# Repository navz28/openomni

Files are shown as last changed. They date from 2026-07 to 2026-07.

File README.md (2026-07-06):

# OpenOmni 🏃‍♂️🕹️

**Treadmill omnidireccional pasiva, DIY e imprimible en 3D — clon funcional del Virtuix Omni One** con madera, tubo de PVC/fierro, piezas de bicicleta, un resorte de gas hidroneumático y electrónica estilo SlimeVR.

> Objetivo: la misma experiencia (caminar/correr 360° dentro de VR sin marearse) por **~US$250–430** en vez de **US$2,600–3,500**.

## Principio de diseño
Igual que el Omni One, **no hay motores**: un **cuenco cóncavo parabólico** de baja fricción + **calzado deslizante** hacen que la gravedad recentre el pie tras cada paso. Un **brazo articulado posterior** que gira 360° sobre un rodamiento (de bici) sostiene al usuario por un **chaleco**, con un **resorte de gas** para agacharse/saltar. Sensores **IMU** en los pies traducen las zancadas a locomoción, presentándose a la PC como un **mando USB** (sin drivers propietarios).

## Contenido del repo
```
treadmill/
├── README.md                 <- esto
├── index.html                <- SIMULACIÓN INTERACTIVA 3D (Three.js) para GitHub Pages
├── geminideepresearch.txt    <- investigación de partida sobre el Omni One
├── docs/
│   ├── 01-lista-componentes.md   <- BOM por subsistema + costos  (ENTREGABLE 1)
│   ├── 02-diagrama-fuerzas.md     <- física + hidráulica + IK     (ENTREGABLE 2)
│   └── 03-referencia-woodt.md     <- armado en madera (octágono, video/WoODT)
├── cad/
│   ├── openomni.scad             <- modelo 3D paramétrico         (ENTREGABLE 3)
│   ├── README.md                 <- cómo renderizar/exportar STL
│   ├── assembly.png / side.png   <- renders del conjunto
│   └── *.stl                     <- piezas imprimibles exportadas
└── firmware/                     <- código + drivers de sensores  (ENTREGABLE 4)
    ├── README.md                 <- cableado, librerías, flasheo
    ├── openomni_protocol.h       <- trama pie→hub (0x55 + seq + CRC16)
    ├── foot_tracker/             <- ESP32-C3 + IMU + FSR (×2)
    ├── hub/                      <- ESP32-S3 → mando USB
    └── pc_bridge.py              <- driver PC alterno (modo serie)
```

## Subsistemas (resumen)
| # | Subsistema | Material clave | Ref. |
|---|---|---|---|
| A | Cuenco cóncavo 13° Ø1.2 m (**octágono de 8 módulos**, estilo WoODT) | contrachapado + piel laminada + HDPE/hardboard + silicona | docs/01 §A |
| B | Estructura + base | fierro 40–50 mm / madera + **lastre 25–30 kg** | docs/01 §B |
| C | Brazo articulado + hub 360° + arnés | tubo acero + **rodamiento/pedalier de bici** + **gas strut** | docs/01 §C |
| D | Calzado deslizante | impreso 3D + **PTFE/UHMW** | docs/01 §D |
| E | Trackers de pie | ESP32-C3 + MPU-9250 + FSR + LiPo | firmware/ |
| F | Hub / puente PC | ESP32-S3 (mando USB) | firmware/ |

## Simulación interactiva (webapp)
`index.html` es un **gemelo digital** en Three.js (autocontenido, para **GitHub Pages**):
- **Humanoide paramétrico** (peso 40–120 kg, altura 1.50–2.00 m) que **camina** en el cuenco.
- **Brazo hidráulico tipo mochila** con **hub que gira 360°** e **IK de 2 eslabones** que se adapta a la talla; botón **«Dejarse caer»** que comprime el gas strut.
- **Flechas de fuerza** en vivo (peso, normal, recentrado, arnés, strut) con lecturas numéricas.
- **Cuenco octagonal** de 8 módulos; **piezas impresas 3D coloreadas** (naranja) e **hidráulica** (turquesa) con leyenda.
- **Ensamblaje animado** (botones Ensamblar/Explotar) y **descargas STL**.

Preview local (tienes node): `npx serve .` y abre `http://localhost:3000` (o abre `index.html` en tu Chromium). Despliegue en Pages: ver abajo.

## Números de diseño (del análisis de fuerzas)
- Usuario máx **113 kg** (W=1110 N); pendiente del cuenco **13°** → recentrado ≤250 N/paso.
- Fricción objetivo **μ < 0.12** (PTFE/UHMW + silicona) = requisito #1.
- Chaleco: **600 N** horiz + 350 N vert. Brazo inferior **tubo 40×40×3** (SF 1.9). Poste **50×50×3** (SF 3.3).
- **Vuelco: hay que lastrar ≥25–30 kg** o vuelca en los saltos (por eso el Omni pesa 70 kg a propósito).

## Orden de construcción sugerido
1. **Cuenco** (A): corta las 16 costillas con la plantilla `cad → rib_template.stl`, ensámblalas radiales, forra, alisa y sella. Prueba la fricción con el calzado antes de seguir.
2. **Base + poste + lastre** (B).
3. **Hub + brazo + arnés** (C): monta el rodamiento de bici, los eslabones y el gas strut; ajusta para tu altura.
4. **Calzado** (D): imprime, pega los PTFE.
5. **Electrónica** (E/F): flashea los 2 pies + el hub, calibra el "adelante", mapea el stick en SteamVR.

## Estado
- [x] Investigación consolidada (+ referencia de armado en madera WoODT)
- [x] Lista de componentes (BOM)
- [x] Diagrama de fuerzas y cálculos (+ física de la hidráulica + IK)
- [x] Modelo 3D en OpenSCAD (renders + STL validados)
- [x] Firmware trackers + hub + puente PC (protocolo validado)
- [x] Webapp interactiva (humanoide, fuerzas, ensamblaje, hidráulica)
- [ ] **Siguiente:** construir el prototipo del cuenco y medir la fricción real (μ) del par superficie/PTFE.

## Desplegar en GitHub Pages
El repo ya está listo (git inicializado y commiteado). Para publicarlo:
```bash
# 1) re-autenticar gh (el token del keyring caducó)
gh auth login
# 2) crear el repo y subir  (público para que Pages funcione en cuenta free)
gh repo create openomni --public --source=. --remote=origin --push
# 3) activar Pages sirviendo desde la raíz de main
gh api -X POST repos/:owner/openomni/pages -f source[branch]=main -f source[path]=/ 2>/dev/null || \
  echo "Actívalo a mano: Settings → Pages → Branch: main / (root)"
```
La app quedará en `https://<usuario>.github.io/openomni/`. Los STL (`cad/*.stl`) se sirven junto a la web para las descargas.

## Fuentes de la investigación
- Virtuix Omni One (specs, patentes, SDK): `geminideepresearch.txt`
- Builds DIY de referencia (ángulo de cuenco 13–15°, deslizadores): [Hackaday](https://hackaday.com/2014/02/18/low-budget-omnidirectional-treadmill/), [Instructables TolDish](https://www.instructables.com/TolDish-a-DIY-Omnidirectional-Treadmill/)
- Tracking de pies open-source: [SlimeVR-Tracker-ESP](https://github.com/SlimeVR/SlimeVR-Tracker-ESP)

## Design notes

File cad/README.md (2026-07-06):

# OpenOmni — Modelo 3D (OpenSCAD)

Modelo **paramétrico** de toda la treadmill en `openomni.scad`. Cambiando las variables de la cabecera (radio `R`, ángulo del borde `edge_angle`, nº de costillas `n_ribs`, etc.) se re-genera todo, incluidas las plantillas de corte.

## Requisitos
OpenSCAD 2021.01+ (ya instalado: `/usr/bin/openscad`).

## Ver el conjunto en la GUI
```bash
openscad cad/openomni.scad
```

## Seleccionar qué pieza mostrar/exportar
La variable `part` elige el objeto. Valores: `assembly`, `bowl`, `rib_template`, `overshoe`, `sensor_case`, `arm_hub`.

## Exportar STL de las piezas imprimibles
```bash
cd cad
openscad -o overshoe.stl    -D 'part="overshoe"'     openomni.scad   # calzado deslizante (x2, uno espejado)
openscad -o sensor_case.stl -D 'part="sensor_case"'  openomni.scad   # carcasa tracker IMU (x2)
openscad -o arm_hub.stl     -D 'part="arm_hub"'       openomni.scad   # abrazadera/hub del brazo
openscad -o rib_template.stl -D 'part="rib_template"' openomni.scad   # plantilla de UNA costilla
```
> `rib_template` es una lámina de 4 mm: imprímela, pégala sobre el contrachapado y usa el perfil para cortar las 16 costillas con sierra de calar. Las marcas grabadas cada 100 mm son las líneas de radio.

## Renderizar imágenes
```bash
DISPLAY=:0 openscad -o assembly.png --imgsize=1100,850 \
  --camera=0,0,0,62,0,32,0 --viewall --autocenter \
  --colorscheme=Tomorrow -D 'part="assembly"' openomni.scad
```
Ya generadas: `assembly.png` (isométrica) y `side.png` (lateral).

## Imprimir el calzado espejado
El pie derecho es el modelo tal cual; para el izquierdo, espeja en el laminador (o añade `mirror([0,1,0])` antes de `overshoe()`).

## Parámetros clave (cabecera del .scad)
| Variable | Valor | Significado |
|---|---|---|
| `R` | 600 | radio útil del cuenco (mm) |
| `edge_angle` | 13 | pendiente en el borde (°) — **no subir**, ver análisis de fuerzas |
| `n_ribs` | 16 | costillas radiales |
| `k` | derivado | coef. de la parábola `z=k·r²` |

## Piezas del modelo
- **Cuenco** (`bowl` + costillas): dish parabólico + 16 costillas radiales.
- **Estructura**: aro base, largueros, poste trasero 50×50, lastre.
- **Brazo articulado**: hub rotatorio, 2 eslabones, bisagra, gas strut, placa de chaleco.
- **Calzado** (`overshoe`): suela con rocker, 3 almohadillas PTFE Ø55, ranuras de correa, pod del sensor.
- **Carcasa sensor** (`sensor_case`): caja 52×40×26 con postes para ESP32 y ranura USB-C/LED.
- **Hub imprimible** (`arm_hub`): abraza el tubo del eslabón y aloja el rodamiento de bici (Ø42).

## Nota
Es un modelo de **diseño/fabricación y visualización**, no un gemelo CAD con tolerancias de máquina. Las piezas de madera/acero se cortan con las plantillas y las dimensiones de la BOM; las piezas imprimibles (calzado, carcasas, hub, abrazaderas) salen directas a STL.

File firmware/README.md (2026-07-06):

# OpenOmni — Firmware

Sistema de tracking de pies estilo **SlimeVR** adaptado a la treadmill omnidireccional. La treadmill es **pasiva** (no tiene motores); el firmware solo lee sensores y traduce el movimiento de los pies en locomoción para el juego.

## Arquitectura

```
   PIE IZQUIERDO                 PIE DERECHO
 ┌──────────────┐             ┌──────────────┐
 │ ESP32-C3     │             │ ESP32-C3     │
 │ + MPU-9250   │             │ + MPU-9250   │
 │ + FSR talon  │             │ + FSR talon  │
 │ + LiPo       │             │ + LiPo       │
 └──────┬───────┘             └──────┬───────┘
        │  ESP-NOW (2.4GHz, broadcast, 100 Hz)
        └───────────────┬────────────┘
                        ▼
                ┌───────────────┐
                │ HUB ESP32-S3  │  fusiona -> vector de locomocion
                │ USB HID nativo│  "soft decoupling" (rumbo de los pies)
                └───────┬───────┘
                        │ USB  (se ve como MANDO estandar)
                        ▼
                   PC / SteamVR / juego
```

- `foot_tracker/` — firmware del tracker de pie (×2). Driver I2C del IMU + fusión Mahony + detección de zancada + envío ESP-NOW.
- `hub/` — firmware del receptor. Recibe ambos pies, fusiona y **se presenta como un mando USB** (sin instalar drivers en la PC).
- `openomni_protocol.h` — trama compartida (preámbulo `0x55` + seq + CRC16), inspirada en el formato de los Foot Trackers del Omni One.

## ¿Por qué "mando USB" y no un driver propietario?

El hub ESP32-S3 usa USB HID nativo (TinyUSB) y aparece como un **gamepad estándar**. Así:
- **No hay que instalar ningún driver** en Windows/Linux.
- Funciona en **SteamVR** (locomoción por stick), en juegos planos y en cualquier motor.
- El stick izquierdo = vector de caminar; botón 1 = correr.

> Para *soft decoupling* real (caminar hacia un lado mientras miras a otro, como el Omni One) se puede escribir además un **driver OpenVR** que inyecte el vector en el espacio del jugador. Es opcional; el modo mando ya da locomoción omnidireccional relativa al cuerpo.

## Hardware y cableado (drivers de sensores)

### Tracker de pie (×2) — ESP32-C3
| Señal | Pin ESP32-C3 | A |
|---|---|---|
| I2C SDA | GPIO8 | MPU-9250 SDA |
| I2C SCL | GPIO9 | MPU-9250 SCL |
| FSR (ADC) | GPIO3 | divisor FSR↔10 kΩ a GND |
| LED estado | GPIO10 | LED + R330 a GND |
| VBAT (ADC) | GPIO2 | divisor 1:1 de la LiPo |
| 3V3 / GND | — | alimentación IMU y FSR |

**FSR (sensor de pisada):** `3V3 —[FSR]— A0 —[10kΩ]— GND`. Al pisar baja la resistencia → sube el ADC. Umbral en el código: `fsr > 400` (ajústalo).

**IMU:** el driver I2C está incluido en `foot_tracker.ino` (no usa librería externa). Detecta MPU-9250 (`WHO_AM_I=0x71`), MPU-6500 (`0x70`) o MPU-9255 (`0x73`). Config: accel ±4 g, gyro ±500 dps, DLPF 41 Hz, 200 Hz.
> Nota: la fusión es de **6 ejes** (accel+gyro). Es robusta para el rumbo a corto plazo de cada zancada. Si tu IMU trae magnetómetro (AK8963 en el MPU-9250, o un ICM-20948), puedes añadir su lectura para rumbo **absoluto** sin deriva — marcado en el código dónde iría.

### Hub — ESP32-S3
- Solo USB al PC. Botón **BOOT (GPIO0)** = recalibrar "adelante".
- (Opcional) OLED SSD1306 por I2C para ver estado/batería.

## Librerías necesarias

Todas vienen con el **core arduino-esp32 (v3.x)** — no hay que instalar terceros:
- `Wire`, `WiFi`, `esp_now` (ambos sketches)
- `USB`, `USBHIDGamepad` (solo el hub, requiere ESP32-S3)

Instala el core desde el Boards Manager de Arduino IDE: *"esp32 by Espressif"* (≥3.0.0).

## Flashear

### Trackers de pie
1. Abre `foot_tracker/foot_tracker.ino`.
2. En **un** tracker deja `#define THIS_FOOT FOOT_LEFT`; en el otro cámbialo a `FOOT_RIGHT`.
3. Placa: *ESP32C3 Dev Module*. Sube.

### Hub
1. Abre `hub/hub.ino`.
2. Placa: *ESP32S3 Dev Module*. En **Tools → USB Mode** elige **"USB-OTG (TinyUSB)"** y **USB CDC On Boot: Enabled**.
3. Sube. Al reconectar, el PC lo detecta como **mando**.

> Con `arduino-cli` (si lo instalas):
> ```bash
> arduino-cli compile -b esp32:esp32:esp32c3 firmware/foot_tracker
> arduino-cli compile -b esp32:esp32:esp32s3 firmware/hub
> ```

## Uso / calibración

1. Enciende los dos trackers (LED **verde fijo** = IMU OK; parpadeo rápido = fallo IMU).
2. Conecta el hub al PC.
3. Párate en el cuenco mirando al frente, pon los pies rectos y **mantén BOOT** ~0.3 s para fijar el "adelante".
4. Camina: deslizar el pie hacia atrás en el cuenco = avanzar; la velocidad escala con lo rápido que deslizas. Correr fuerte activa el botón "sprint".
5. En SteamVR/juego, asigna locomoción al **stick izquierdo** del mando nuevo.

## Algoritmo (resumen)

Por pie, cada 10 ms:
1. Mahony → cuaternión → **yaw** (rumbo) y matriz de rotación.
2. Acel. body → mundo, resta 1 g → aceleración lineal.
3. Integra a velocidad; **ZUPT** (zero-velocity update) cuando el FSR marca contacto y la aceleración es baja → mata la deriva.
4. Proyecta la velocidad sobre el rumbo del pie → **velocidad de deslizamiento hacia atrás** = caminar.

El hub toma el pie de apoyo activo (en contacto y más rápido), aplica zona muerta + suavizado, resta el rumbo calibrado (**desacople**) y saca `X=strafe`, `Y=adelante` al stick.

## Opción sin ESP32-S3: puente por Serial

Si no consigues un ESP32-S3, usa un ESP32 normal como hub por **USB serie** y el script `pc_bridge.py` crea el mando virtual en la PC (Windows con `vgamepad`, Linux con `python-uinput`). Ver cabecera del script.

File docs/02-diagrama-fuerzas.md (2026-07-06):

# OpenOmni — Diagrama de Fuerzas y Cálculos Estructurales

Análisis estático (con factores dinámicos) de los subsistemas que soportan carga. Todo pasivo: **la gravedad hace el trabajo de recentrar el pie**; la estructura solo debe (a) dejar deslizar el pie con poca fricción y devolverlo al centro, y (b) sostener al usuario sin volcar.

## 0. Parámetros de diseño

| Símbolo | Valor | Nota |
|---|---|---|
| m_max | 113 kg | usuario máximo (= Omni One) |
| W | **1110 N** | peso usuario = m·g (g=9.81) |
| R | 600 mm | radio útil del cuenco |
| perfil | z = k·r² | parábola |
| θ_borde | 13° | pendiente en el borde |
| k | 1.924×10⁻⁴ /mm | de tan13° = 2·k·R |
| z_borde | 69.3 mm | profundidad del centro respecto al borde |
| Φ (factor dinámico) | 2.5–3.0× | pico de impacto al correr/saltar |
| μ_objetivo | **0.08–0.12** | PTFE/UHMW + lubricante de silicona sobre superficie sellada |

---

## 1. Geometría del cuenco y auto-recentrado (self-centering)

En el radio `r`, la pendiente local es `tanθ(r) = 2·k·r`. El peso del pie apoyado (`W_pie`, hasta = W en apoyo monopodal) se descompone:

```
        superficie
         del cuenco
            \  N (normal) = W·cosθ
             \ ^
              \|
   pie ●───────\────────► F_rest = W·sinθ  (tangencial, hacia el CENTRO)
               |\
               | \
       W (peso)v  \θ
                   \
   ────────────────•──────  hacia el centro del cuenco
```

- **Fuerza de recentrado** (la que devuelve el pie al centro): `F_rest = W_pie · sinθ`
- **Normal:** `N = W_pie · cosθ`
- **Condición para que el pie DESLICE de vuelta solo** (no se quede pegado): `F_rest > μ·N` ⟹ **`tanθ > μ`**

Mapa del cuenco (con W_pie = W = 1110 N, apoyo en un pie):

| r (mm) | θ | z (mm) | F_rest (N) | μ necesario para retornar |
|---:|----:|---:|---:|---:|
| 0 | 0° | 0 | 0 | — |
| 100 | 2.2°  | 1.9  | 43  | <0.038 |
| 200 | 4.4°  | 7.7  | 85  | <0.077 |
| 300 | 6.6°  | 17.3 | 127 | <0.115 |
| 400 | 8.8°  | 30.8 | 169 | <0.154 |
| 500 | 10.9° | 48.1 | 210 | <0.192 |
| 600 | 13.0° | 69.3 | 250 | <0.231 |

**Lecturas de diseño:**
- Con **μ ≈ 0.10**, el pie se auto-recentra para `r > 260 mm` (donde tanθ=0.10). Dentro de ese radio hay una pequeña "zona muerta" central donde la fricción retiene el pie — irrelevante: el siguiente paso lo corrige. Es el mismo compromiso del Omni One.
- **No bajar de 13° ni subir mucho:** el borde exige F_rest=250 N por paso. Más pendiente = más fatiga del tibial (la queja clásica); menos = el usuario deriva y choca contra el arnés. **13° es el punto dulce** (coincide con los builds DIY de 13–15°).
- Toda la ingeniería de fricción (PTFE/UHMW + silicona) existe para mantener **μ < 0.12**. Es el requisito #1 del proyecto.

---

## 2. Cuerpo libre del usuario + arnés (fuerza de lean)

Para "caminar en el sitio" el usuario se **inclina** contra el chaleco (péndulo invertido apoyado en los pies y sostenido atrás por el brazo).

```
              cabeza
               ●
              /|            φ = ángulo de inclinación
             / |
   chaleco  /  |  P_h  (horizontal, el brazo lo retiene)
    ═════► ▓   |──►
           /   |
          /    | W_user (peso, vertical)
         /     v
    pie ●──────┴──  cuenco
```

Modelando el cuerpo como péndulo invertido, la fuerza horizontal que el chaleco/brazo debe reaccionar:

`P_h ≈ W_user · tanφ`

| Actividad | φ (lean) | P_h |
|---|---|---|
| Caminar suave | 10° | 196 N |
| Trote | 15° | 297 N |
| Sprint | 25° | 517 N |
| Sprint + pico dinámico (×1.3) | — | **≈ 600–670 N** |

**Carga de diseño del arnés:**
- Horizontal: **P_h = 600 N**
- Vertical (el usuario "cuelga" parte del peso / el gas strut la sostiene): **P_v = 350 N** (≈0.3·W)

---

## 3. Cuerpo libre del brazo articulado

Geometría (origen en el poste trasero, a ras de piso):
- Collar rotatorio del brazo en el poste, a **h_c = 350 mm**.
- Chaleco a **h_v = 1050 mm** de alto y **d_v = 550 mm** por delante del poste.
- Brazo carga P_h (horizontal) y P_v (vertical) en el chaleco.

```
           chaleco (P_h→, P_v↓)
                ●·····························►  P_h = 600 N
               /:                          
              / : Δy = h_v−h_c = 700 mm    
   eslabón   /  :                          
   superior /   :                          
           /    :                          
   junta  ◉ ....:                          
         /      d_v = 550 mm               
        / eslabón inferior                 
collar ◎══════════ poste ═══════ (rodamiento de giro 360°)
       ║ h_c=350                           
   ════╩════ placa base ═══ piso           
```

**Momento flector en el collar** (peor caso, sumando conservador):
- por P_h:  M₁ = P_h · Δy = 600 N × 0.70 m = **420 N·m**
- por P_v:  M₂ = P_v · d_v = 350 N × 0.55 m = **193 N·m**
- **M_collar ≈ 610 N·m**

Este momento lo reaccionan el rodamiento del hub (§4) y el poste (§5).

**Verificación del tubo del brazo** (acero 30×30×2 mm SHS):
- Z ≈ 2.06×10³ mm³ ; σ = M₁/Z (en el tramo más cargado) — el eslabón inferior ve el momento completo cerca del collar.
- Con M=610 N·m: σ = 610000/2060 = **296 MPa** → ¡supera el límite de acero dulce (250 MPa)!
- **Corrección:** usar tubo **40×40×3 mm** (Z ≈ 4.6×10³ mm³) → σ = 133 MPa, **SF ≈ 1.9**. ✔️ *(Actualiza B/C: el eslabón inferior y el collar en 40×40×3, no 30×30×2.)*

---

## 4. Rodamiento del hub rotatorio (giro 360°)

El momento M_collar debe transformarse en un **par de fuerzas** entre dos rodamientos separados una distancia `s` en el eje del poste:

`F_bearing = M_collar / s`

| Separación s | F por rodamiento | Componente sugerido |
|---|---|---|
| 250 mm | 2440 N | marginal para 6008 (C≈16 kN estático, pero fatiga) |
| **400 mm** | **1525 N** | **6008 / buje de bici / cazoleta pedalier** ✔️ |
| turntable | — | rodamiento lazy-susan con **rating de momento** directo ✔️ |

**Recomendación:** separar los rodamientos ≥400 mm en el poste **o** usar un rodamiento de **rótula/trailer (cónico ahusado)** rescatado —baratos y con alta capacidad de momento—. Un **pedalier de bici** sellado va perfecto para el rodamiento inferior de empuje; un **buje de rueda** para el superior. Engrasar y sellar contra polvo.

---

## 5. Poste/mástil y su base

El poste (tubo **50×50×3 mm**, §B2) es corto (0.35 m) pero transmite el momento a la placa base:

- Momento en la base ≈ P_h · h_v = 600 × 1.05 = **630 N·m**
- SHS 50×50×3: Z = 8.34×10³ mm³ → σ = 630000/8340 = **75.5 MPa**, **SF ≈ 3.3** ✔️
- **Punto crítico = la unión poste↔placa base.** Soldar con cartelas (gussets) en las 4 caras, o si es atornillado, placa de 6 mm con 4× M10 y triángulos de refuerzo. No confiar en una sola soldadura de filete.

---

## 6. Estabilidad al vuelco (¡el punto más crítico!)

El usuario se inclina hacia adelante; el brazo lo retiene y **jala el poste hacia adelante**, tendiendo a **volcar la máquina hacia el frente** (rotación sobre el borde delantero de la huella).

```
   P_h=600N →  ● chaleco (h=1.05m)
              /|
             / |          Momento de vuelco:
            /  |          M_vuelco = P_h · h_v = 630 N·m
    poste  ◎   |
   ═════════╤══╪═══════════════════════╗
   borde    │  CG_máquina    CG_usuario ║ borde
   trasero  │  (500N)        (1110N)    ║ DELANTERO ← pivote de vuelco
            0  0.5m          0.6m      1.2m
```

Momentos respecto al **borde delantero** (x = 1.2 m):
- **Vuelco:** M_v = 600 N × 1.05 m = **630 N·m**
- **Resistente (máquina):** 500 N × (1.2−0.5) = 350 N·m
- **Resistente (usuario centrado):** 1110 N × (1.2−0.6) = 666 N·m
- Total resistente = 1016 N·m → **SF = 1.6** *si el usuario está centrado.*

⚠️ **Problema:** durante un **salto** el peso del usuario desaparece un instante → SF cae a **350/630 = 0.56 → ¡VUELCA!**

**Solución (obligatoria):** no depender del peso del usuario. Igual que el Omni One pesa 70 kg **a propósito**, hay que **lastrar la base**:

- Añadir **≈25–30 kg de lastre** (bloques de concreto, arena en cajones del marco, o pavers) en la mitad trasera → M_máquina sube a ~900–1000 N·m sin el usuario → **SF ≥ 2.0** aun en salto. ✔️
- **o** anclar la placa base al piso (si es instalación fija).
- **o** ampliar la huella con **outriggers/patas delanteras** a 1.4–1.5 m.

> El lastre es casi gratis (arena/concreto) y es la forma correcta de resolverlo. **Diséñalo pesado.**

---

## 7. Resorte de gas (compliance vertical, agacharse/saltar)

El gas strut sostiene la fracción vertical `P_v ≈ 350 N` y devuelve suave al usuario tras agacharse.

- Fuerza de extensión del strut ≈ P_v ajustada por la relación de palanca de su montaje en el brazo. Montado casi vertical en el eslabón: **F_strut ≈ 300–400 N**.
- **Componente:** cilindro de **silla de oficina** (regulable, ~US$10) o amortiguador de portón de auto de **250–400 N**. Carrera ≥120 mm para permitir un squat parcial.
- El giro 360° del hub + la junta abisagrada horizontal permiten girarse; el gas strut da el eje vertical.

### 7.1 Física del brazo hidráulico (¿cómo sostiene al usuario al "dejarse caer"?)

El brazo va **como una mochila**: placa en la espalda → 2 eslabones → hub que **gira 360°** sobre un rodamiento de bici en el poste trasero. Es un **mecanismo pasivo** (juntas de revolución + muelle de gas). Al dejarte caer hacia atrás, el brazo baja y el **resorte de gas** te frena y sostiene.

**Muelle neumático (gas spring):** un pistón encierra N₂ a presión `P₀`. Al comprimir el vástago una distancia `x`, el volumen baja y la presión sube según un proceso casi adiabático:

```
P · Vᵞ = const     (γ ≈ 1.4 para N₂)
```

La fuerza de soporte es la presión por el área efectiva del vástago:

```
F(x) = P(x) · A_ef ,   con  P(x) = P₀ · ( V₀ / (V₀ − A_ef·x) )ᵞ
```

- **Muelle progresivo:** como `P` crece al comprimir, `F` aumenta con la caída → cuanto más te dejas caer, más te empuja (auto-limita el descenso). Ideal para un "catch" suave.
- **Amortiguación viscosa:** el sellado con aceite añade `F_d = c·v` (proporcional a la velocidad del vástago) → elimina el rebote elástico. Por eso un gas strut "cae lento y sube lento".
- **Dimensionado:** para sostener `P_v ≈ 0.32·W` en un usuario de 113 kg → `F ≈ 350 N` de extensión nominal. Un cilindro de silla de oficina (100 kg de rating) o un amortiguador de portón de 300–400 N cumplen. La palanca real depende de dónde lo montes en el eslabón (ver el modelo 3D / webapp).

### 7.2 Cinemática: ¿hace falta cinemática inversa (IK)?

**En el aparato real: NO.** El brazo no tiene motores ni control; es **compliante** y sigue tu espalda por pura mecánica (como un brazo de flexo/lámpara). Los grados de libertad:
1. **Rotación del hub (yaw, 360°)** → te giras y el brazo te sigue alrededor de la plataforma.
2. **Junta abisagrada vertical (pitch)** → subes/bajas, te agachas/saltas; aquí actúa el gas strut.
3. (Opcional) una **rótula** en la placa de la espalda → inclinación lateral del torso.

Con esos 3 GDL pasivos, el extremo alcanza tu espalda en cualquier pose sin cálculo alguno.

**En la simulación (webapp): SÍ uso IK de 2 eslabones** — sólo para *dibujar* el brazo persiguiendo el punto de la mochila cuando cambias **altura/peso/giro/inclinación**. Ley de cosenos para el ángulo del codo:

```
D = |espalda − hub|            (alcance requerido)
cos(codo) = (D² − L₁² − L₂²) / (2·L₁·L₂)
hombro    = atan2(Δy, Δh) + acos( (D² + L₁² − L₂²) / (2·L₁·D) )
```

Así el gemelo digital muestra cómo el brazo **se ajusta solo** a personas de distinta talla (prueba los sliders de peso 40–120 kg y altura 1.50–2.00 m). En hardware, ese ajuste lo hace la física; en pantalla, la IK.

---

## 8. Esfuerzos de contacto (verificación de materiales)

**Almohadilla del calzado (PTFE/UHMW):**
- Fuerza normal pico por pie = Φ·W = 2.5 × 1110 = **2775 N**
- Pad Ø55 mm → A = 2376 mm² → presión = **1.17 MPa**
- PTFE resistencia a compresión ~10–20 MPa → **OK**, pero el PTFE **fluye (creep)** bajo carga sostenida → usar **UHMW o PTFE con carga de vidrio/bronce** para durabilidad. ✔️

**Piel del cuenco entre costillas:**
- A 14 costillas, separación en el borde = 2π·600/14 = **269 mm**.
- Piel de 3–4 mm bajo parche de ~1 MPa flecta demasiado en 269 mm.
- **Corrección:** doble piel (luan 3 mm + hardboard 3 mm) **o** 16 costillas (separación ≤235 mm) **o** superficie superior rígida de HDPE 2 mm que reparte la carga. ✔️

---

## 9. Resumen: cargas de diseño → especificación de componentes

| Elemento | Carga de diseño | Especificación resultante |
|---|---|---|
| Superficie del cuenco | μ < 0.12 | PTFE/UHMW/hardboard sellado + silicona |
| Fuerza de recentrado | 250 N máx (borde) | pendiente 13° |
| Chaleco/arnés | 600 N horiz + 350 N vert | arnés acolchado, anclaje impreso reforzado |
| Eslabón inferior del brazo | M = 610 N·m | **tubo acero 40×40×3 mm** (SF 1.9) |
| Rodamiento del hub | 1525 N/rod. (s=400) | pedalier+buje de bici, o cónico de trailer, o lazy-susan |
| Poste/mástil | M = 630 N·m | **SHS 50×50×3** + cartelas (SF 3.3) |
| Estabilidad al vuelco | 630 N·m vuelco | **lastre ≥25–30 kg** o anclaje (SF ≥2.0) |
| Gas strut | 300–400 N | cilindro silla oficina / amortiguador portón |
| Pad del calzado | 2775 N (1.17 MPa) | UHMW / PTFE cargado, Ø≥55 mm |
| Costillas del cuenco | parche ~1 MPa | ≥16 costillas o doble piel |

> **Cambios que este análisis fuerza en la BOM:** (1) el eslabón inferior del brazo sube a **40×40×3 mm** (no 30×30); (2) añadir **lastre de 25–30 kg** a la base; (3) **16 costillas** o doble piel en el cuenco. Ya reflejar esto en `01-lista-componentes.md` en la próxima revisión.

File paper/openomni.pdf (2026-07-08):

## OpenOmni: diseño e ingeniería de una cinta omnidireccional pasiva de realidad virtual, imprimible en 3D y de bajo costo

Nicolás Álvarez

July 8, 2026

## Abstract

OpenOmni es una plataforma de locomoción omnidireccional pasiva para realidad virtual (VR), concebida como una réplica funcional y económica del Virtuix Omni One, construible con madera, tubo de acero, componentes de bicicleta, un resorte de gas y piezas impresas en 3D. El sistema resuelve el conflicto vestibular de la VR permitiendo caminar y correr físicamente en el sitio: un cuenco cóncavo de baja fricción recentra el pie por gravedad, mientras un brazo articulado posterior –montado como una mochila y girando 360 ◦
sobre un rodamiento central– sostiene al usuario. Este documento presenta la biomecánica del cuenco, la cinemática del brazo mediante parámetros de Denavit–Hartenberg, la física del muelle neumático, el análisis de fuerzas y estabilidad, la estructura mecánica, y la electrónica de seguimiento inercial de los pies. Se incluye un gemelo digital interactivo (Three.js) que valida la geometría y visualiza las fuerzas en vivo.

## 1 Introducción

La locomoción ha sido el problema abierto de la VR durante más de una década: el conflicto entre el sistema visual (que percibe movimiento) y el vestibular (que permanece estático) provoca cinetosis. Las cintas omnidireccionales resuelven el conflicto haciendo que el usuario camine realmente. El Virtuix Omni One es el referente comercial: una base cóncava de baja fricción más un brazo de soporte que reemplaza al aro de contención de generaciones previas. Su costo (US$2.600–3.500) motiva este trabajo: OpenOmni reproduce sus principios con un presupuesto de US$250–430 usando materiales de ferretería e impresión 3D.
El sistema es pasivo: no emplea motores para la locomoción ni para el soporte. La gravedad y la geometría hacen el trabajo. Esto simplifica drásticamente la construcción y elimina la seguridad funcional asociada a actuadores.

## 2 Arquitectura del sistema

OpenOmni se compone de seis subsistemas (Fig. 1):

1. Cuenco cóncavo (∅1.2 m, pendiente de borde 13 ◦ ):
superficie parabólica de baja fricción.
2. Estructura: octágono de madera sobre patas, con lastre anti-vuelco.
3. Brazo articulado + arnés: 3 GDL pasivos, girando 360 ◦
sobre un rodamiento central.
4. Sistema hidráulico: resorte de gas que soporta la carga vertical.
5. Calzado deslizante: sobre-zapatos con almohadillas de PTFE/UHMW.
6. Electrónica: sensores inerciales en los pies (estilo SlimeVR) que se presentan al PC como un mando USB.

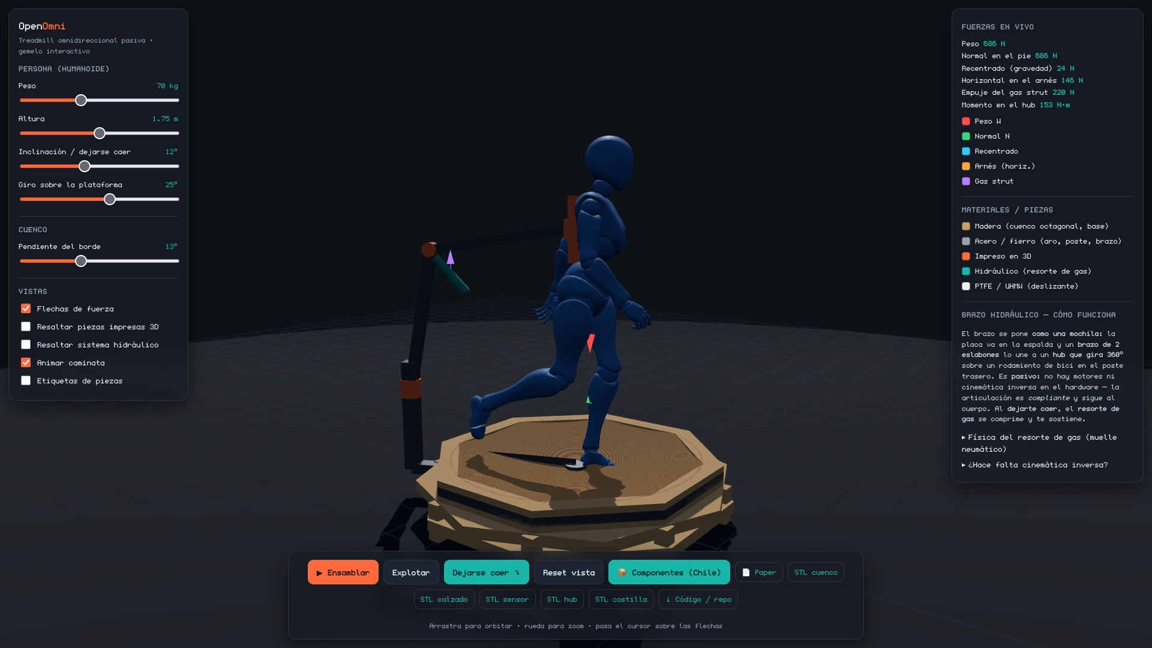
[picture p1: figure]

Figure 1: Gemelo digital interactivo de OpenOmni (Three.js). El maniquí (70 kg) camina en el cuenco octagonal; el brazo posterior tipo mochila y su resorte de gas aparecen a la izquierda. Las flechas representan las fuerzas en vivo.

3 | Cuenco cóncavo: | geometría y
| biomecánica

La superficie sigue un perfil parabólico de revolución

| z(r) = k r²
, | k =
| | tan θb 2R
, | (1)

con radio R = 0.6 m y pendiente de borde θb = 13 ◦
| | , de
donde k = 1.924e − 4 /mm y una profundidad central de 69 mm.
En el radio r, la pendiente local es tan θ(r) = 2kr. El peso del pie apoyado Wp (hasta el peso corporal W en apoyo monopodal) se descompone en una normal N = Wp cos θ y una componente tangencial de recentrado
Frec = Wp sin θ(r), | (2)

que devuelve el pie al centro. Para que el pie deslice de vuelta (y no se quede pegado) se requiere Frec > µN, es decir
tan θ(r) > µ | (3)

Con un coeficiente de fricción objetivo µ ≈ 0.10 (PTFE/UHMW con lubricante de silicona), el pie se autorecentra para r ≳ 0.26 m. El compromiso es fino: una pendiente mayor fatiga el tibial (250 N por paso en el borde para W = 1110 N), mientras que una menor deja al usuario derivar contra el arnés. La ingeniería de fricción (µ < 0.12) es el requisito de diseño primario.

## 4 Cinemática del brazo de soporte

El brazo es una cadena serial de 3 GDL desde un rodamiento central hasta el punto de la mochila en la espalda (Fig. 4). Sus parámetros de Denavit–Hartenberg (estándar) se listan en la Tabla 1.

i | articulación | ai | αi | di
1 | giro (yaw) | a1 | 90 ◦ | d1
2 | hombro | L1 | 0
- 0
3 | codo | L2 | 0
- 0
Table 1: | Parámetros DH del brazo. | θ1 | (giro sobre la
plataforma) sigue al usuario; a1 es el brazo radial del centro al poste; d1 la altura del hombro; L1, L2 los eslabones (= 0.7 m).

La matriz homogénea de cada eslabón es

i−1Ai =

cθi −sθi
cαi
| | sθi
| | sαi | aicθi
sθi | cθi
| cαi | −cθi
sαi | aisθi
0 | sαi | cαi | di
0 | 0 | 0 | 1

, (4)

y la pose del efector final (chaleco) es 0T3 = 0A1

1A2

2A3.

Naturaleza pasiva. En el hardware no hay actuadores ni cinemática inversa: las tres articulaciones son de revolución libres (rodamientos) y el resorte de gas provee compliancia en el eje vertical. El brazo sigue al cuerpo por pura mecánica, como una lámpara de brazo articulado. El giro θ1 mantiene el brazo detrás del usuario al rotar 360 ◦

Gemelo digital. Para dibujar el brazo persiguiendo la espalda (que se mueve con la altura, el giro y la inclinación), el simulador sí resuelve la cinemática inversa planar de 2 eslabones. Dado el objetivo (px, py) en el plano del brazo y su alcance D =

q
p

x + p
y

,

cos θ3 =

D² − L

2
1 − L

2
2
2L1L2
, | (5)

θ2 = atan2(py, px) + arccosD² + L

2
1 − L

2
2
2L1D

. (6)

## 5 Sistema hidráulico: el resorte de gas

El soporte vertical lo provee un muelle neumático (gas strut): un pistón encierra nitrógeno a presión P0 (Fig. 2). Al comprimir el vástago una distancia x, el volumen disminuye y, en un proceso casi adiabático,

P V γ = const, | γ ≈ 1.4, | (7)

por lo que la fuerza de soporte

F(x) = P(x) Aef, P(x) = P0

V0
V0 − Aef x

γ
(8)

crece con la compresión: el muelle es progresivo (autolimita la caída). El sellado con aceite añade amortiguación viscosa Fd = c x˙, eliminando el rebote.

Acoplamiento con el brazo. El strut se monta como puente del codo: un extremo en el eslabón inferior a distancia a del codo, el otro en el superior a distancia b. Su longitud queda ligada al ángulo interior del codo φ por la ley de cosenos

L

2
s = a

2 + b

2 − 2ab cos φ | (9)

Así, al agacharse o dejarse caer, el codo se cierra (φ disminuye), el strut se comprime y la fuerza progresiva sostiene al usuario. El dimensionado nominal (F ≈ 0.32 W ≈ 350 N, carrera ≥ 120 mm) se cubre con un cilindro de silla de oficina o un amortiguador de portón.

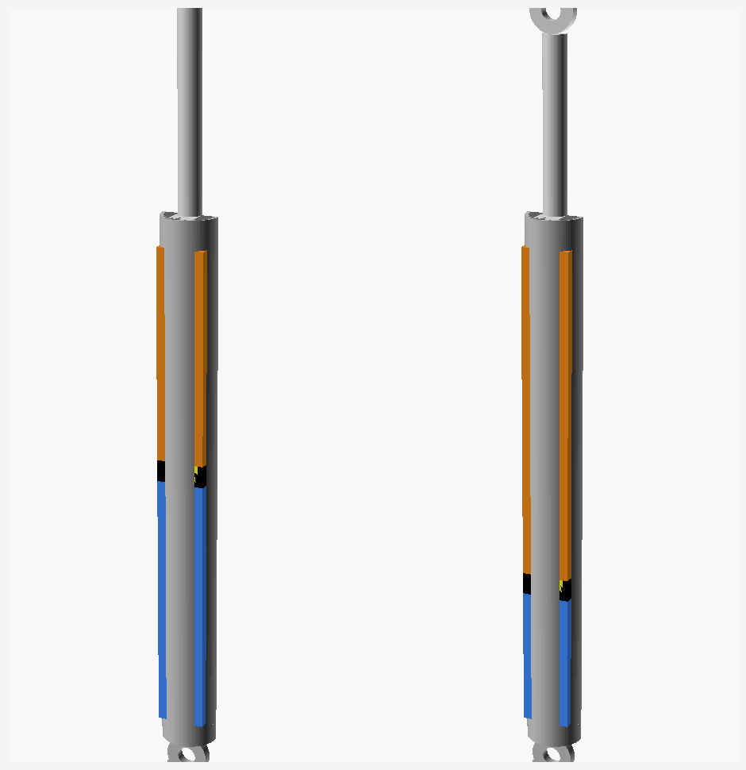
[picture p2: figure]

Figure 2: Corte del resorte de gas modelado en OpenSCAD (extendido vs. comprimido): cámara de gas N2 (azul), aceite de amortiguación (ámbar), pistón y vástago.

## 6 Fuerzas y estabilidad

Modelando al usuario como péndulo invertido apoyado en los pies y sostenido atrás por el brazo, la fuerza horizontal en el arnés al inclinarse un ángulo ϕ es Ph = W tan ϕ (hasta ∼ 600 N en sprint). El momento en el rodamiento del hub M = Ph hv ≈ 630 Nm debe reaccionarse como par de fuerzas (dos rodamientos separados) o con un rodamiento de momento (rueda de remolque).

Vuelco. El momento de vuelco Mv = Phhv es crítico durante un salto (cuando el peso del usuario desaparece). La solución –como en el Omni One, que pesa 70 kg a propósito– es lastrar la base con 25 –30 kg (arena/concreto) para un factor de seguridad ≥ 2 sin depender del usuario.

## 7 Estructura mecánica y juntas

La base es un octágono de ocho módulos de madera (siguiendo el patrón de vigas radiales tipo rayos + bloque central + deck de terciado laminado). Las uniones críticas radial–centro se ejecutan con tornillos estructurales 8x80 mm más adhesivo D3 (no sólo clavos). El giro emplea un rodamiento central (rueda de remolque o plato giratorio), muy superior a un raíl perimetral en facilidad y suavidad.

Juntas impresas en 3D. Las abrazaderas impresas actúan como locator/clamp: la carga real la toma un perno de acero pasante (Fig. 3), nunca el plástico. Los alojamientos de tubo se diseñan con +0.4 mm de tolerancia (FDM), pared ≥ 4 mm e inserto roscado metálico para el apriete.

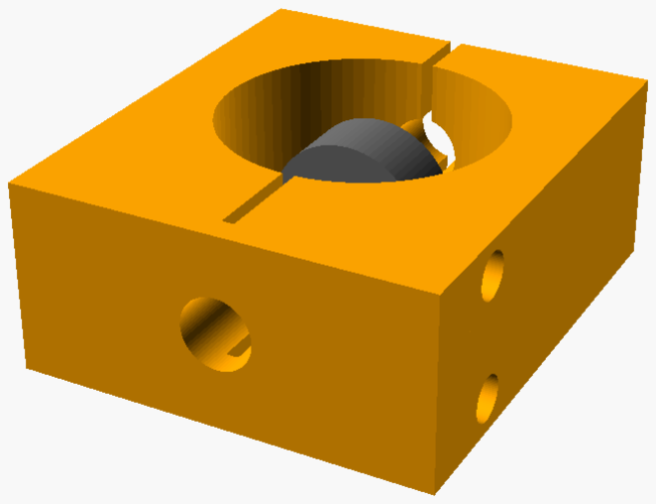
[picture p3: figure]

Figure 3: Junta realista (OpenSCAD): abrazadera impresa (naranja) con alojamiento de tubo, ranura de split-clamp, pernos M5 y perno M8 pasante de acero que soporta la carga; el ojal de acero del strut se monta en ese perno.

## 8 Electrónica y firmware

Cada pie lleva un microcontrolador ESP32-C3 con una IMU de 9 ejes (MPU-9250) y un sensor de presión (FSR) en el talón. La orientación se estima con un filtro de Mahony a 200 Hz; la aceleración lineal se integra con ZUPT (zero-velocity update) para estimar la velocidad de deslizamiento del pie. Los datos viajan por ESP-NOW a un hub ESP32-S3 que fusiona el vector de locomoción – con desacople de rumbo: la dirección proviene de los pies, no de la cabeza– y se presenta al PC como un mando USB HID, funcionando en SteamVR y cualquier juego sin drivers propietarios.

## 9 Gemelo digital interactivo

Todo el diseño se valida en un gemelo digital web (Three.js) desplegado en GitHub Pages (Fig. 4). Permite variar peso (40–120 kg) y altura (1.5–2.0 m) del maniquí, inclinarlo, girarlo y ensamblarlo/explotarlo, mostrando las fuerzas en vivo y un panel de componentes con enlaces de compra. Sirve como herramienta de diseño y de comunicación del sistema.

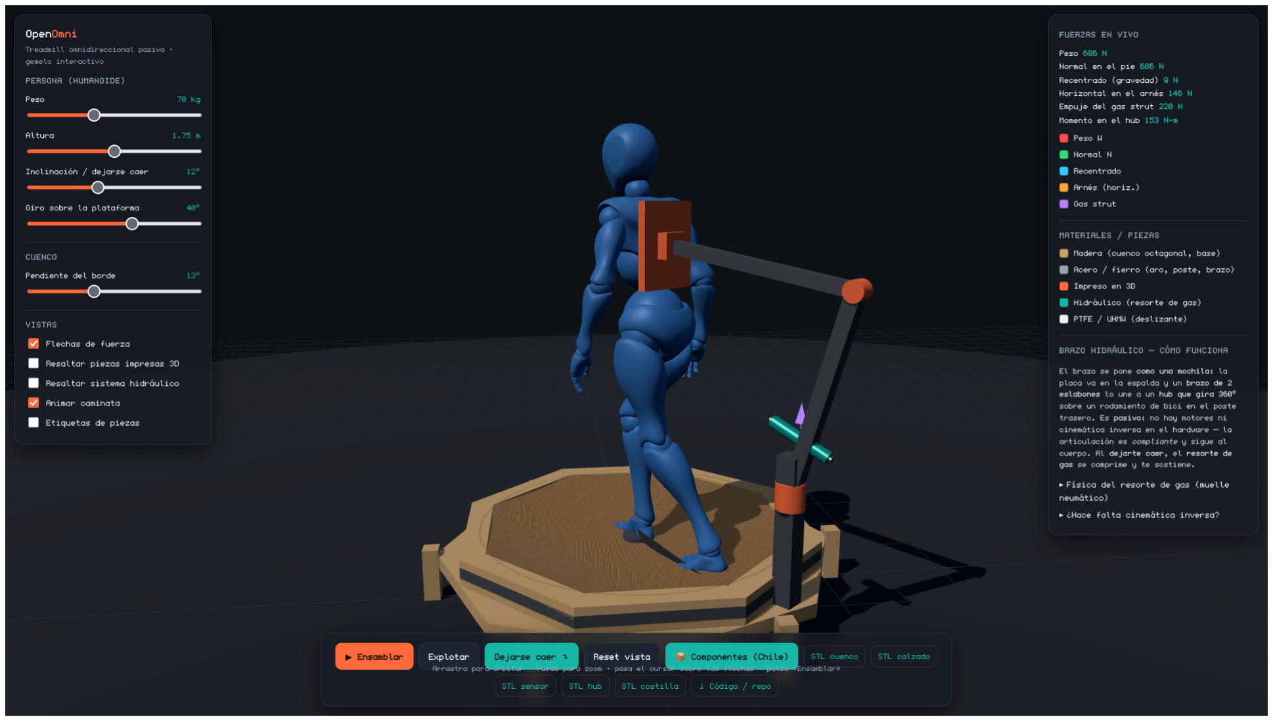
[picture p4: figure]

Figure 4: Torre de giro central: placa base + rodamiento de giro (pistas y bolas) + carro giratorio con brazo radial y poste; el pedestal central fijo sube por el eje del rodamiento y sostiene la plataforma (cuenco) arriba.

## 10 Torre de giro: rodamiento central y caminos de carga

La observación inicial era que, en el Omni One, el anillo giratorio del brazo y la plataforma parecían compartir el mismo rodamiento central sobre una base estructural. El diseño de OpenOmni lo resuelve con un rodamiento de giro (slewing ring: pista externa fija, pista interna giratoria y bolas intermedias) y, sobre todo, separando dos caminos de carga para que ninguna función comprometa a la otra:

- Peso del usuario (W): cuenco → pedestal central fijo (que sube por el bore del rodamiento) → placa base → piso. El rodamiento no soporta el peso axial del usuario.
- Giro del brazo: carro giratorio → pista interna → bolas → pista externa fija → placa base → piso. El rodamiento toma sólo el giro y el momento de vuelco del brazo, M ≈ Ph h ≲ 600 N · 1.0 m (Sección 6).

El apilado, de abajo hacia arriba, es: placa base con patas (anti-vuelco) · rodamiento (pistas + bolas) · brazo/carro · pedestal · plataforma (cuenco) arriba. Un único slewing ring también podría cargar ambas funciones —están diseñados para carga combinada axial+radial+momento—, pero separar los caminos abarata la pieza (basta un rodamiento de menor capacidad axial) y desacopla el desgaste del giro de la seguridad estructural bajo el usuario.

Pendiente de validar en prototipo: rigidez del voladizo del cuenco sobre el pedestal (el borde a r = R genera momento sobre el eje central), holgura/precarga del rodamiento para un giro suave sin juego, y verificación experimental del reparto real del rodamiento del Omni One frente a esta arquitectura de caminos separados.

## 11 Conclusiones

OpenOmni demuestra que los principios del Omni One – cuenco parabólico de baja fricción con recentrado gravitacional, brazo articulado compliante y seguimiento inercial– son reproducibles con materiales de ferretería e impresión 3D a ∼1/8 del costo. Los puntos críticos son la fricción del cuenco (µ < 0.12), el lastre anti-vuelco y el uso de acero (no plástico) en las juntas cargadas. El gemelo digital y los modelos paramétricos (OpenSCAD) hacen el diseño auditable y modificable.

## 12 Apéndice: firmware del tracker de pie (extracto)

El código completo está en firmware/foot_tracker/. Se muestran el filtro de Mahony (fusión de acelerómetro + giroscopio a cuaternión) y el bucle principal, que integra la aceleración lineal con ZUPT y obtiene la velocidad de deslizamiento del pie hacia atrás –la señal de “caminar”– enviada por ESP-NOW al hub.

void mahonyUpdate(float gx,float gy,float gz,float ax,float ay,float az,float dt){
float recipNorm;
float halfvx,halfvy,halfvz;
float halfex,halfey,halfez;

if(!(ax==0 && ay==0 && az==0)){
recipNorm = 1.0f/sqrtf(ax*ax+ay*ay+az*az); ax*=recipNorm; ay*=recipNorm; az*=recipNorm; // gravedad estimada desde el quaternion
halfvx = q1*q3 - q0*q2;
halfvy = q0*q1 + q2*q3;
halfvz = q0*q0 - 0.5f + q3*q3;
// error = producto cruz medido x estimado halfex = (ay*halfvz - az*halfvy);
halfey = (az*halfvx - ax*halfvz);
halfez = (ax*halfvy - ay*halfvx);
if(twoKi>0.0f){
integralFBx += twoKi*halfex*dt; integralFBy += twoKi*halfey*dt; integralFBz += twoKi*halfez*dt; gx += integralFBx; gy += integralFBy; gz += integralFBz;
}
gx += twoKp*halfex; gy += twoKp*halfey; gz += twoKp*halfez;
}
// integra el rate de giro
gx*=0.5f*dt; gy*=0.5f*dt; gz*=0.5f*dt;
float qa=q0, qb=q1, qc=q2;
q0 += (-qb*gx - qc*gy - q3*gz);
q1 += ( qa*gx + qc*gz - q3*gy);
q2 += ( qa*gy - qb*gz + q3*gx);
q3 += ( qa*gz + qb*gy - qc*gx);
recipNorm = 1.0f/sqrtf(q0*q0+q1*q1+q2*q2+q3*q3); q0*=recipNorm; q1*=recipNorm; q2*=recipNorm; q3*=recipNorm;
}

void loop(){
uint32_t now=micros();
float dt=(lastMicros==0)?0.005f:(now-lastMicros)*1e-6f; lastMicros=now; if(dt<=0 || dt>0.1f) dt=0.005f;

float ax,ay,az,gx,gy,gz;
imuRead(ax,ay,az,gx,gy,gz); mahonyUpdate(gx,gy,gz,ax,ay,az,dt);

// aceleracion lineal en el mundo (quita la gravedad)
float wx,wy,wz; bodyAccelToWorld(ax,ay,az,wx,wy,wz);
wx*=G; wy*=G; wz=(wz-1.0f)*G; | // resta 1g en Z-mundo
float amag=sqrtf(wx*wx+wy*wy);

int fsr=analogRead(PIN_FSR);
bool contact = fsr > 400; | // FSR: contacto con el cuenco
velX += wx*dt; velY += wy*dt; | // integra velocidad horizontal

// ZUPT: contacto + poca aceleracion => pie quieto => resetea deriva if(contact && amag < 0.6f){
if(millis()-lastZupt > 40){ velX*=0.5f; velY*=0.5f; }
} else { lastZupt=millis(); }
velX*=0.995f; velY*=0.995f; | // fuga lenta anti-runaway

// rumbo del pie y velocidad de deslizamiento HACIA ATRAS = caminar float yaw=yawDeg();
float fwdx=cosf(yaw*DEG_TO_RAD), fwdy=sinf(yaw*DEG_TO_RAD);
float vForward = velX*fwdx + velY*fwdy;
float backSpeed = (vForward < 0) ? -vForward : 0.0f;
backSpeed = constrain(backSpeed, 0.0f, 3.5f);
if(millis()-lastTx >= 10){ | // envia a 100 Hz por ESP-NOW
lastTx=millis();
sendPacket(yaw, contact?backSpeed:0.0f, contact?1:0);
}
}

## References

[1] Virtuix, Omni One — documentación técnica y patentes (US 20230356099 A1; US 11,247,126).
[2] SlimeVR, SlimeVR-Tracker-ESP, seguimiento inercial de código abierto.

[3] WoODT — Wooden Omni Directional Treadmill, movesilently.de.
[4] R. Mahony et al., “Nonlinear complementary filters on the special orthogonal group,” IEEE Trans. Automatic Control, 2008.
[5] J. J. Craig, Introduction to Robotics: Mechanics and Control, parámetros de Denavit–Hartenberg.

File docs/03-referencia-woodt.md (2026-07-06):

# Referencia de armado en madera — Video + WoODT

Fuente pedida por el usuario: **"DIY Virtuix Omni-Directional Treadmill Build Log"** (YouTube `oi5DU2JfRhU`, 2015) y el proyecto hermano **WoODT (Wooden Omni Directional Treadmill)** de movesilently.de — el build en madera mejor documentado.

> No pude extraer fotogramas del video directamente, pero recuperé el método de construcción del proyecto WoODT asociado, que es la referencia canónica del armado en madera.

## Hallazgos clave (validan nuestro diseño)

1. **El cuenco es un OCTÁGONO de 8 módulos.** La forma de "sartén"/dish se arma en **8 módulos** (gajos) independientes que se unen en octágono. → Responde tu pregunta: **sí, un octágono de madera es la forma correcta y probada.**
2. **Superficie curva = varias capas de contrachapado fino pegadas** sobre la estructura de soporte de cada módulo (laminado sobre las costillas). Es exactamente nuestro enfoque costillas + piel.
3. **Aro de acero soldado**, pintado, fijado a una **base de madera** para dar estabilidad y proteger el piso. → Coincide con nuestro aro estructural + base + lastre.
4. Permite **caminar, correr, agacharse y sentarse** — el rango de movimiento objetivo.

## Cómo esto cambia el diseño OpenOmni

- **Cuenco por módulos (octágono):** en vez de cortar un anillo circular perfecto, se construyen **8 gajos de 45°** idénticos. Cada gajo = 2 costillas laterales (perfil parabólico) + travesaños + **piel de contrachapado fino laminado en 2–3 capas** (se curva sola al pegarla sobre las costillas). Ventajas: cortes rectos, fácil de transportar, se atornillan entre sí formando el octágono.
- **Superficie deslizante** encima del laminado (HDPE/hardboard sellado + silicona), igual que antes.
- **Aro perimetral octagonal** de fierro (8 tramos rectos soldados/atornillados) sobre **base de madera** con el lastre.

Esto **simplifica el corte** (todo son 8 piezas iguales) y es lo que el modelo 3D y la webapp ahora representan como octágono.

## Otras referencias del mismo ecosistema
- Instructables **TolDish** (cuenco + deslizadores de muebles).
- **Omnidirectional treadmill** (Wikipedia) para el panorama de tipos.

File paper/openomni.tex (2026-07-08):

\documentclass[10pt,twocolumn]{article}
\usepackage[utf8]{inputenc}
\usepackage[T1]{fontenc}
\usepackage{lmodern}
\usepackage{amsmath,amssymb}
\usepackage{graphicx}
\usepackage{booktabs}
% --- reemplazo minimo de siunitx (no instalado) ---
\providecommand{\SI}[2]{#1\,#2}
\providecommand{\SIrange}[3]{#1--#2\,#3}
\providecommand{\si}[1]{#1}
\providecommand{\meter}{m}\providecommand{\milli}{m}\providecommand{\kilo}{k}
\providecommand{\gram}{g}\providecommand{\newton}{N}\providecommand{\hertz}{Hz}
\providecommand{\per}{/}\providecommand{\degree}{\ensuremath{^\circ}}
\usepackage[margin=1.8cm]{geometry}
\usepackage{float}
\usepackage[hidelinks]{hyperref}
\usepackage{caption}
\captionsetup{font=small}
\usepackage{listings}
\lstset{basicstyle=\ttfamily\scriptsize,breaklines=true,columns=fullflexible,
  keepspaces=true,showstringspaces=false,frame=single,xleftmargin=3pt,aboveskip=4pt,belowskip=2pt}

\title{\textbf{OpenOmni}: dise\~no e ingenier\'ia de una cinta omnidireccional
pasiva de realidad virtual, imprimible en 3D y de bajo costo}
\author{Nicol\'as \'Alvarez}
\date{\today}

\begin{document}
\maketitle

\begin{abstract}
\noindent
OpenOmni es una plataforma de locomoci\'on omnidireccional \emph{pasiva} para realidad
virtual (VR), concebida como una r\'eplica funcional y econ\'omica del \emph{Virtuix
Omni One}, construible con madera, tubo de acero, componentes de bicicleta, un resorte
de gas y piezas impresas en 3D. El sistema resuelve el conflicto vestibular de la VR
permitiendo caminar y correr f\'isicamente en el sitio: un cuenco c\'oncavo de baja
fricci\'on recentra el pie por gravedad, mientras un brazo articulado posterior --montado
como una mochila y girando \SI{360}{\degree} sobre un rodamiento central-- sostiene al
usuario. Este documento presenta la biomec\'anica del cuenco, la cinem\'atica del brazo
mediante par\'ametros de Denavit--Hartenberg, la f\'isica del muelle neum\'atico, el
an\'alisis de fuerzas y estabilidad, la estructura mec\'anica, y la electr\'onica de
seguimiento inercial de los pies. Se incluye un \emph{gemelo digital} interactivo
(Three.js) que valida la geometr\'ia y visualiza las fuerzas en vivo.
\end{abstract}

\section{Introducci\'on}
La locomoci\'on ha sido el problema abierto de la VR durante m\'as de una d\'ecada: el
conflicto entre el sistema visual (que percibe movimiento) y el vestibular (que permanece
est\'atico) provoca cinetosis. Las cintas omnidireccionales resuelven el conflicto
haciendo que el usuario camine realmente. El \emph{Virtuix Omni One} es el referente
comercial: una base c\'oncava de baja fricci\'on m\'as un brazo de soporte que reemplaza
al aro de contenci\'on de generaciones previas. Su costo (US\$2.600--3.500) motiva este
trabajo: \textbf{OpenOmni} reproduce sus principios con un presupuesto de
US\$250--430 usando materiales de ferreter\'ia e impresi\'on 3D.

El sistema es \emph{pasivo}: no emplea motores para la locomoci\'on ni para el soporte.
La gravedad y la geometr\'ia hacen el trabajo. Esto simplifica dr\'asticamente la
construcci\'on y elimina la seguridad funcional asociada a actuadores.

\section{Arquitectura del sistema}
OpenOmni se compone de seis subsistemas (Fig.~\ref{fig:webui}):
\begin{enumerate}\itemsep2pt
  \item \textbf{Cuenco c\'oncavo} ($\varnothing$\SI{1.2}{\meter}, pendiente de borde
  \SI{13}{\degree}): superficie parab\'olica de baja fricci\'on.
  \item \textbf{Estructura}: oct\'agono de madera sobre patas, con lastre anti-vuelco.
  \item \textbf{Brazo articulado + arn\'es}: 3 GDL pasivos, girando \SI{360}{\degree}
  sobre un rodamiento central.
  \item \textbf{Sistema hidr\'aulico}: resorte de gas que soporta la carga vertical.
  \item \textbf{Calzado deslizante}: sobre-zapatos con almohadillas de PTFE/UHMW.
  \item \textbf{Electr\'onica}: sensores inerciales en los pies (estilo SlimeVR) que se
  presentan al PC como un mando USB.
\end{enumerate}

\begin{figure}[H]
\centering

\caption{Gemelo digital interactivo de OpenOmni (Three.js). El maniqu\'i (\SI{70}{\kilo\gram})
camina en el cuenco octagonal; el brazo posterior tipo mochila y su resorte de gas
aparecen a la izquierda. Las flechas representan las fuerzas en vivo.}
\label{fig:webui}
\end{figure}

\section{Cuenco c\'oncavo: geometr\'ia y biomec\'anica}
La superficie sigue un perfil parab\'olico de revoluci\'on
\begin{equation}
z(r) = k\,r^{2}, \qquad k=\frac{\tan\theta_{b}}{2R},
\end{equation}
con radio $R=\SI{0.6}{\meter}$ y pendiente de borde $\theta_b=\SI{13}{\degree}$, de donde
$k=\SI{1.924e-4}{\per\milli\meter}$ y una profundidad central de \SI{69}{\milli\meter}.

En el radio $r$, la pendiente local es $\tan\theta(r)=2kr$. El peso del pie apoyado
$W_p$ (hasta el peso corporal $W$ en apoyo monopodal) se descompone en una normal
$N=W_p\cos\theta$ y una componente tangencial de \emph{recentrado}
\begin{equation}
F_{\text{rec}} = W_p\,\sin\theta(r),
\end{equation}
que devuelve el pie al centro. Para que el pie deslice de vuelta (y no se quede pegado)
se requiere $F_{\text{rec}}>\mu N$, es decir
\begin{equation}
\boxed{\ \tan\theta(r) > \mu\ }
\end{equation}
Con un coeficiente de fricci\'on objetivo $\mu\approx0.10$ (PTFE/UHMW con lubricante de
silicona), el pie se auto-recentra para $r\gtrsim\SI{0.26}{\meter}$. El compromiso es
fino: una pendiente mayor fatiga el tibial (\SI{250}{\newton} por paso en el borde para
$W=\SI{1110}{\newton}$), mientras que una menor deja al usuario derivar contra el arn\'es.
La ingenier\'ia de fricci\'on ($\mu<0.12$) es el requisito de dise\~no primario.

\section{Cinem\'atica del brazo de soporte}
El brazo es una cadena serial de 3 GDL desde un rodamiento central hasta el punto de la
mochila en la espalda (Fig.~\ref{fig:bearing}). Sus par\'ametros de
Denavit--Hartenberg (est\'andar) se listan en la Tabla~\ref{tab:dh}.

\begin{table}[H]
\centering
\begin{tabular}{ccccc}
\toprule
$i$ & articulaci\'on & $a_i$ & $\alpha_i$ & $d_i$ \\
\midrule
1 & giro (yaw) & $a_1$ & \SI{90}{\degree} & $d_1$ \\
2 & hombro     & $L_1$ & \SI{0}{\degree}  & $0$ \\
3 & codo       & $L_2$ & \SI{0}{\degree}  & $0$ \\
\bottomrule
\end{tabular}
\caption{Par\'ametros DH del brazo. $\theta_1$ (giro sobre la plataforma) sigue al usuario;
$a_1$ es el brazo radial del centro al poste; $d_1$ la altura del hombro; $L_1,L_2$ los
eslabones ($=\SI{0.7}{\meter}$).}
\label{tab:dh}
\end{table}

La matriz homog\'enea de cada eslabón es
\begin{equation}
{}^{i-1}\!A_i=
\begin{bmatrix}
c_{\theta_i} & -s_{\theta_i}c_{\alpha_i} & s_{\theta_i}s_{\alpha_i} & a_i c_{\theta_i}\\
s_{\theta_i} &  c_{\theta_i}c_{\alpha_i} & -c_{\theta_i}s_{\alpha_i} & a_i s_{\theta_i}\\
0 & s_{\alpha_i} & c_{\alpha_i} & d_i\\
0&0&0&1
\end{bmatrix},
\end{equation}
y la pose del efector final (chaleco) es
$\,{}^{0}T_3={}^{0}\!A_1\,{}^{1}\!A_2\,{}^{2}\!A_3$.

\paragraph{Naturaleza pasiva.} En el hardware \emph{no hay actuadores ni cinem\'atica
inversa}: las tres articulaciones son de revoluci\'on libres (rodamientos) y el resorte
de gas provee compliancia en el eje vertical. El brazo sigue al cuerpo por pura mec\'anica,
como una l\'ampara de brazo articulado. El giro $\theta_1$ mantiene el brazo detr\'as del
usuario al rotar \SI{360}{\degree}.

\paragraph{Gemelo digital.} Para \emph{dibujar} el brazo persiguiendo la espalda (que se
mueve con la altura, el giro y la inclinaci\'on), el simulador s\'i resuelve la cinem\'atica
inversa planar de 2 eslabones. Dado el objetivo $(p_x,p_y)$ en el plano del brazo y su
alcance $D=\sqrt{p_x^2+p_y^2}$,
\begin{align}
\cos\theta_3 &= \frac{D^2-L_1^2-L_2^2}{2L_1L_2},\\
\theta_2 &= \operatorname{atan2}(p_y,p_x) + \arccos\!\frac{D^2+L_1^2-L_2^2}{2L_1D}.
\end{align}

\section{Sistema hidr\'aulico: el resorte de gas}
El soporte vertical lo provee un \emph{muelle neum\'atico} (gas strut): un pist\'on
encierra nitr\'ogeno a presi\'on $P_0$ (Fig.~\ref{fig:strut}). Al comprimir el v\'astago
una distancia $x$, el volumen disminuye y, en un proceso casi adiab\'atico,
\begin{equation}
P\,V^{\gamma}=\text{const},\qquad \gamma\approx1.4,
\end{equation}
por lo que la fuerza de soporte
\begin{equation}
F(x)=P(x)\,A_{\text{ef}},\quad
P(x)=P_0\!\left(\frac{V_0}{V_0-A_{\text{ef}}\,x}\right)^{\!\gamma}
\end{equation}
crece con la compresi\'on: el muelle es \emph{progresivo} (auto-limita la ca\'ida). El
sellado con aceite a\~nade amortiguaci\'on viscosa $F_d=c\,\dot{x}$, eliminando el rebote.

\paragraph{Acoplamiento con el brazo.} El strut se monta como \emph{puente del codo}: un
extremo en el eslab\'on inferior a distancia $a$ del codo, el otro en el superior a
distancia $b$. Su longitud queda ligada al \'angulo interior del codo $\varphi$ por la
ley de cosenos
\begin{equation}
\boxed{\ L_s^2 = a^2 + b^2 - 2ab\cos\varphi\ }
\end{equation}
As\'i, al agacharse o dejarse caer, el codo se cierra ($\varphi$ disminuye), el strut se
comprime y la fuerza progresiva sostiene al usuario. El dimensionado nominal
($F\approx0.32\,W\approx\SI{350}{\newton}$, carrera $\geq\SI{120}{\milli\meter}$) se cubre
con un cilindro de silla de oficina o un amortiguador de port\'on.

\begin{figure}[H]
\centering

\caption{Corte del resorte de gas modelado en OpenSCAD (extendido vs.\ comprimido):
c\'amara de gas N$_2$ (azul), aceite de amortiguaci\'on (\'ambar), pist\'on y v\'astago.}
\label{fig:strut}
\end{figure}

\section{Fuerzas y estabilidad}
Modelando al usuario como p\'endulo invertido apoyado en los pies y sostenido atr\'as por
el brazo, la fuerza horizontal en el arn\'es al inclinarse un \'angulo $\phi$ es
$P_h=W\tan\phi$ (hasta $\sim\SI{600}{\newton}$ en sprint). El momento en el rodamiento del
hub $M=P_h\,h_v\approx\SI{630}{\newton\meter}$ debe reaccionarse como par de fuerzas
(dos rodamientos separados) o con un rodamiento de momento (rueda de remolque).

\paragraph{Vuelco.} El momento de vuelco $M_v=P_h h_v$ es cr\'itico durante un salto
(cuando el peso del usuario desaparece). La soluci\'on --como en el Omni One, que pesa
\SI{70}{\kilo\gram} a prop\'osito-- es \textbf{lastrar la base} con
\SI{25}{}--\SI{30}{\kilo\gram} (arena/concreto) para un factor de seguridad
$\geq2$ sin depender del usuario.

\section{Estructura mec\'anica y juntas}
La base es un \textbf{oct\'agono de ocho m\'odulos} de madera (siguiendo el patr\'on de
vigas radiales tipo rayos + bloque central + deck de terciado laminado). Las uniones
cr\'iticas radial--centro se ejecutan con \emph{tornillos estructurales} \SI{8x80}{\milli\meter}
m\'as adhesivo D3 (no s\'olo clavos). El giro emplea \textbf{un rodamiento central} (rueda
de remolque o plato giratorio), muy superior a un ra\'il perimetral en facilidad y suavidad.

\paragraph{Juntas impresas en 3D.} Las abrazaderas impresas act\'uan como
\emph{locator/clamp}: la carga real la toma un \textbf{perno de acero pasante}
(Fig.~\ref{fig:mount}), nunca el pl\'astico. Los alojamientos de tubo se dise\~nan con
$\SI{+0.4}{\milli\meter}$ de tolerancia (FDM), pared $\geq\SI{4}{\milli\meter}$ e inserto
roscado met\'alico para el apriete.

\begin{figure}[H]
\centering
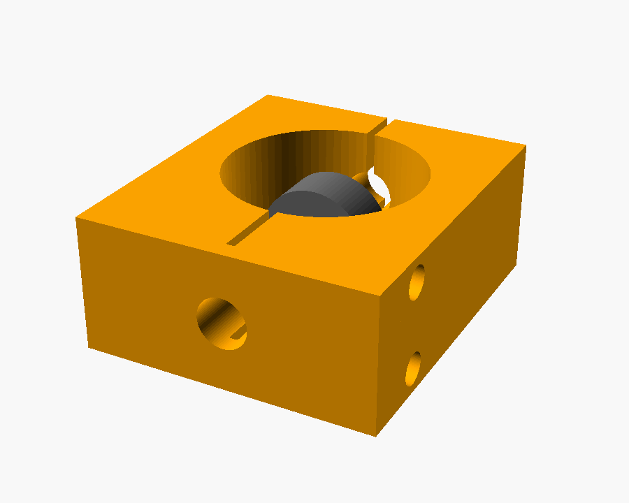
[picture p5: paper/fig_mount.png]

\caption{Junta realista (OpenSCAD): abrazadera impresa (naranja) con alojamiento de tubo,
ranura de \emph{split-clamp}, pernos M5 y \textbf{perno M8 pasante} de acero que soporta la
carga; el ojal de acero del strut se monta en ese perno.}
\label{fig:mount}
\end{figure}

\section{Electr\'onica y firmware}
Cada pie lleva un microcontrolador ESP32-C3 con una IMU de 9 ejes (MPU-9250) y un sensor
de presi\'on (FSR) en el tal\'on. La orientaci\'on se estima con un filtro de Mahony a
\SI{200}{\hertz}; la aceleraci\'on lineal se integra con \emph{ZUPT} (zero-velocity update)
para estimar la velocidad de deslizamiento del pie. Los datos viajan por ESP-NOW a un hub
ESP32-S3 que fusiona el vector de locomoci\'on --con \emph{desacople de rumbo}: la
direcci\'on proviene de los pies, no de la cabeza-- y se presenta al PC como un
\textbf{mando USB HID}, funcionando en SteamVR y cualquier juego sin drivers propietarios.

\section{Gemelo digital interactivo}
Todo el dise\~no se valida en un gemelo digital web (Three.js) desplegado en GitHub Pages
(Fig.~\ref{fig:bearing}). Permite variar peso (\SIrange{40}{120}{\kilo\gram}) y altura
(\SIrange{1.5}{2.0}{\meter}) del maniqu\'i, inclinarlo, girarlo y ensamblarlo/explotarlo,
mostrando las fuerzas en vivo y un panel de componentes con enlaces de compra. Sirve como
herramienta de dise\~no y de comunicaci\'on del sistema.

\begin{figure}[H]
\centering
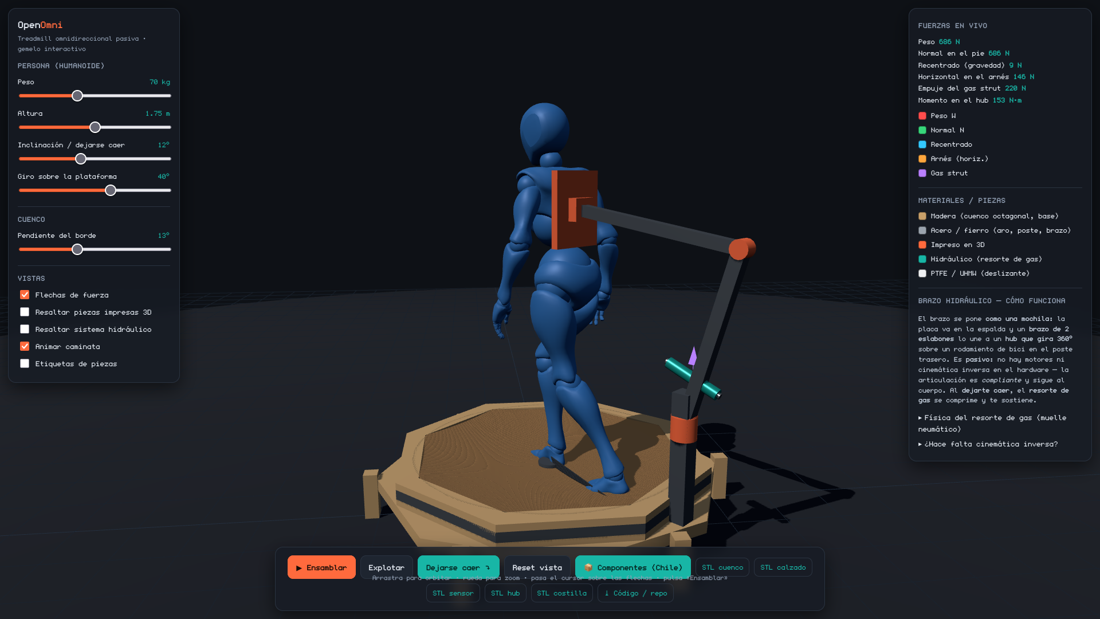
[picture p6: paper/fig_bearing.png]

\caption{Torre de giro central: placa base + rodamiento de giro (pistas y bolas) + carro
giratorio con brazo radial y poste; el pedestal central fijo sube por el eje del rodamiento y
sostiene la plataforma (cuenco) arriba.}
\label{fig:bearing}
\end{figure}

\section{Torre de giro: rodamiento central y caminos de carga}
La observaci\'on inicial era que, en el Omni One, el anillo giratorio del brazo y la plataforma
parec\'ian compartir el \emph{mismo rodamiento central} sobre una base estructural. El dise\~no
de OpenOmni lo resuelve con un \textbf{rodamiento de giro} (\emph{slewing ring}: pista externa
fija, pista interna giratoria y bolas intermedias) y, sobre todo, \textbf{separando dos caminos
de carga} para que ninguna funci\'on comprometa a la otra:
\begin{itemize}\itemsep2pt
\item \textbf{Peso del usuario} ($W$): cuenco $\rightarrow$ \emph{pedestal central fijo} (que sube
por el \emph{bore} del rodamiento) $\rightarrow$ placa base $\rightarrow$ piso. El rodamiento
\emph{no} soporta el peso axial del usuario.
\item \textbf{Giro del brazo}: carro giratorio $\rightarrow$ pista interna $\rightarrow$ bolas
$\rightarrow$ pista externa fija $\rightarrow$ placa base $\rightarrow$ piso. El rodamiento
toma \emph{s\'olo} el giro y el momento de vuelco del brazo,
$M \approx P_h\,h \lesssim \SI{600}{\newton}\cdot\SI{1.0}{\meter}$ (Secci\'on~6).
\end{itemize}
El apilado, de abajo hacia arriba, es: \textbf{placa base con patas} (anti-vuelco) $\cdot$
\textbf{rodamiento} (pistas + bolas) $\cdot$ \textbf{brazo/carro} $\cdot$ \textbf{pedestal} $\cdot$
\textbf{plataforma (cuenco) arriba}. Un \'unico \emph{slewing ring} tambi\'en podr\'ia cargar
ambas funciones ---est\'an dise\~nados para carga combinada axial+radial+momento---, pero
separar los caminos abarata la pieza (basta un rodamiento de menor capacidad axial) y desacopla
el desgaste del giro de la seguridad estructural bajo el usuario.
\vspace{2pt}

\noindent\fbox{\begin{minipage}{0.95\linewidth}\small
\textbf{Pendiente de validar en prototipo:} rigidez del voladizo del cuenco sobre el pedestal
(el borde a $r=R$ genera momento sobre el eje central), holgura/pre\-carga del rodamiento
para un giro suave sin juego, y verificaci\'on experimental del reparto real del rodamiento
del Omni One frente a esta arquitectura de caminos separados.
\end{minipage}}
\vspace{4pt}

\section{Conclusiones}
OpenOmni demuestra que los principios del Omni One --cuenco parab\'olico de baja fricci\'on
con recentrado gravitacional, brazo articulado compliante y seguimiento inercial-- son
reproducibles con materiales de ferreter\'ia e impresi\'on 3D a $\sim$1/8 del costo. Los
puntos cr\'iticos son la fricci\'on del cuenco ($\mu<0.12$), el lastre anti-vuelco y el uso
de acero (no pl\'astico) en las juntas cargadas. El gemelo digital y los modelos
param\'etricos (OpenSCAD) hacen el dise\~no auditable y modificable.

\onecolumn
\section{Ap\'endice: firmware del tracker de pie (extracto)}
El c\'odigo completo est\'a en \texttt{firmware/foot\_tracker/}. Se muestran el filtro de
Mahony (fusi\'on de aceler\'ometro + giroscopio a cuaterni\'on) y el bucle principal, que
integra la aceleraci\'on lineal con \emph{ZUPT} y obtiene la velocidad de deslizamiento
del pie hacia atr\'as --la se\~nal de ``caminar''-- enviada por ESP-NOW al hub.

\begin{lstlisting}[language=C++]
void mahonyUpdate(float gx,float gy,float gz,float ax,float ay,float az,float dt){
    float recipNorm;
    float halfvx,halfvy,halfvz;
    float halfex,halfey,halfez;

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

void loop(){
    uint32_t now=micros();
    float dt=(lastMicros==0)?0.005f:(now-lastMicros)*1e-6f; lastMicros=now;
    if(dt<=0 || dt>0.1f) dt=0.005f;

    float ax,ay,az,gx,gy,gz;
    imuRead(ax,ay,az,gx,gy,gz);
    mahonyUpdate(gx,gy,gz,ax,ay,az,dt);

    // aceleracion lineal en el mundo (quita la gravedad)
    float wx,wy,wz; bodyAccelToWorld(ax,ay,az,wx,wy,wz);
    wx*=G; wy*=G; wz=(wz-1.0f)*G;               // resta 1g en Z-mundo
    float amag=sqrtf(wx*wx+wy*wy);

    int fsr=analogRead(PIN_FSR);
    bool contact = fsr > 400;                    // FSR: contacto con el cuenco

    velX += wx*dt; velY += wy*dt;                // integra velocidad horizontal

    // ZUPT: contacto + poca aceleracion => pie quieto => resetea deriva
    if(contact && amag < 0.6f){
        if(millis()-lastZupt > 40){ velX*=0.5f; velY*=0.5f; }
    } else { lastZupt=millis(); }
    velX*=0.995f; velY*=0.995f;                  // fuga lenta anti-runaway

    // rumbo del pie y velocidad de deslizamiento HACIA ATRAS = caminar
    float yaw=yawDeg();
    float fwdx=cosf(yaw*DEG_TO_RAD), fwdy=sinf(yaw*DEG_TO_RAD);
    float vForward = velX*fwdx + velY*fwdy;
    float backSpeed = (vForward < 0) ? -vForward : 0.0f;
    backSpeed = constrain(backSpeed, 0.0f, 3.5f);

    if(millis()-lastTx >= 10){                   // envia a 100 Hz por ESP-NOW
        lastTx=millis();
        sendPacket(yaw, contact?backSpeed:0.0f, contact?1:0);
    }
}
\end{lstlisting}

\begin{thebibliography}{9}
\small
\bibitem{virtuix} Virtuix, \emph{Omni One} --- documentaci\'on t\'ecnica y patentes
(US 20230356099 A1; US 11,247,126).
\bibitem{slimevr} SlimeVR, \emph{SlimeVR-Tracker-ESP}, seguimiento inercial de c\'odigo abierto.
\bibitem{woodt} \emph{WoODT --- Wooden Omni Directional Treadmill}, movesilently.de.
\bibitem{mahony} R.\ Mahony et al., ``Nonlinear complementary filters on the special
orthogonal group,'' \emph{IEEE Trans.\ Automatic Control}, 2008.
\bibitem{craig} J.\ J.\ Craig, \emph{Introduction to Robotics: Mechanics and Control},
par\'ametros de Denavit--Hartenberg.
\end{thebibliography}

\end{document}

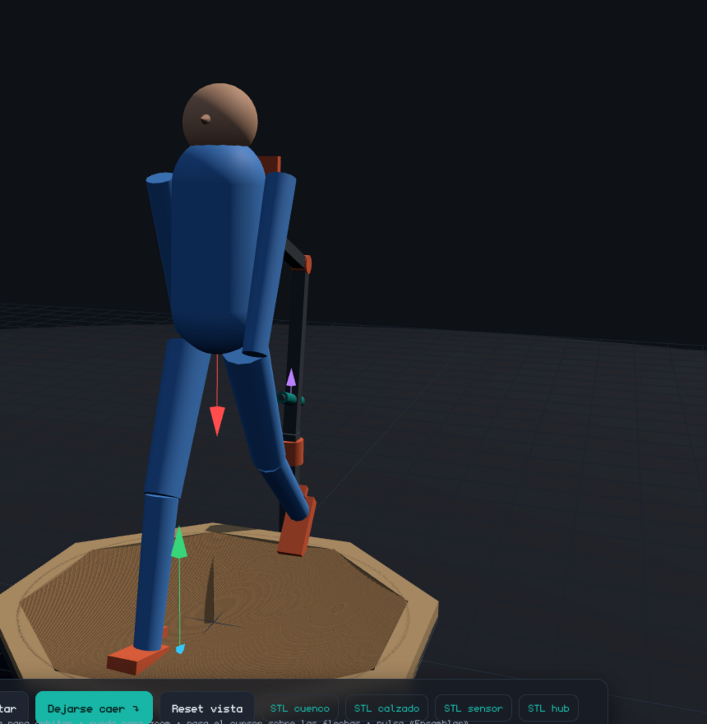
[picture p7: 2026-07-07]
paper/fig_forces.png

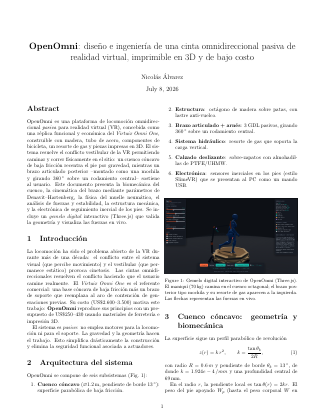
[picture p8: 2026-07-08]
paper/thumb.png

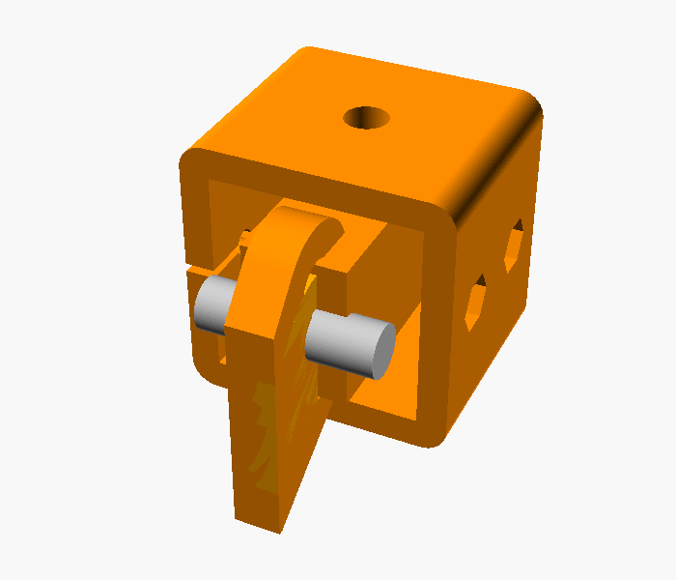
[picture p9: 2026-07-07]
cad/j_elbow.png

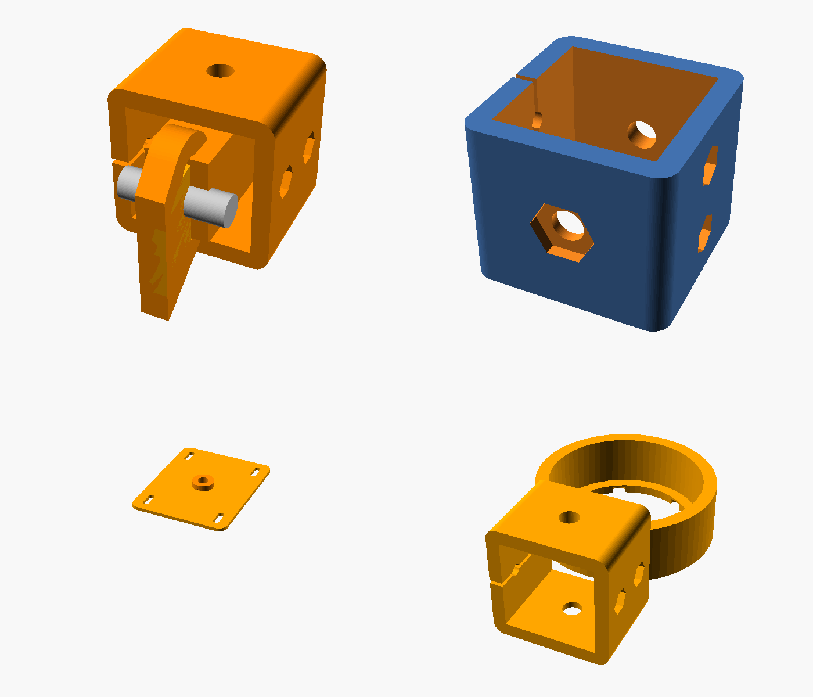
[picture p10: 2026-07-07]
cad/joints_grid.png

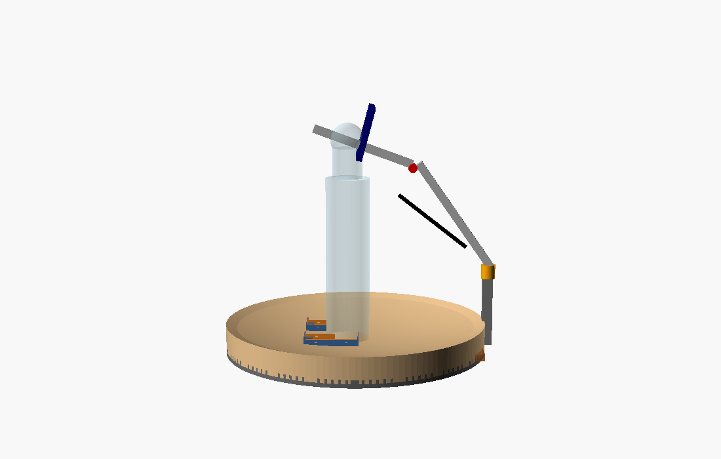
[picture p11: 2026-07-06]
cad/side.png

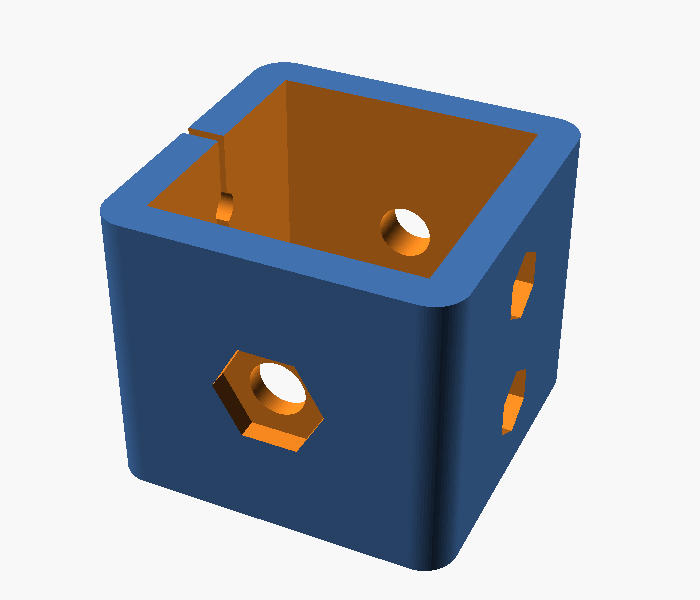
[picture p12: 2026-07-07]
cad/j_clamp.png

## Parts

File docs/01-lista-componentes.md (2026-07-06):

# OpenOmni — Lista de Componentes (BOM)

**Proyecto:** Treadmill omnidireccional pasiva DIY, inspirada en el Virtuix Omni One.
**Principio:** cuenco cóncavo de baja fricción + calzado deslizante + brazo posterior articulado con arnés (sin motores para la locomoción — todo pasivo, la gravedad recentra el pie). Tracking de pies por IMU (estilo SlimeVR) traducido a un mando USB.

**Objetivo dimensional (copiado del Omni One):**
- Diámetro útil del cuenco: **1.20 m**
- Huella total: ~1.20 × 1.50 m
- Carga dinámica de diseño: **hasta 113 kg** de usuario
- Altura de usuario: 1.32–1.92 m

**Filosofía de materiales:** madera (contrachapado + tablero), tubo de PVC, perfil de fierro/acero, rodamientos y piezas rescatadas de **bicicleta**, un **resorte de gas** (hidroneumático) tipo silla de oficina, y piezas **impresas en 3D** para las juntas, carcasas y el calzado.

> Los precios son órdenes de magnitud en USD (mercado general). Casi todo puede abaratarse comprando de segunda mano, rescatando de una bici vieja o sustituyendo por chatarra local. La estimación total DIY ronda **US$180–350** frente a los **US$2,600–3,500** del Omni One.

---

## A. Cuenco cóncavo de baja fricción (la "base")

El corazón mecánico. Perfil parabólico (z = k·r²), radio 600 mm, pendiente en el borde ≈ 13° (rango DIY probado 13–15°). Construcción de **costillas radiales de contrachapado** + piel flexible + superficie deslizante.

| # | Componente | Material / Especificación | Cant. | Costo aprox. |
|---|---|---|---|---|
| A1 | Costillas radiales del cuenco | Contrachapado 15–18 mm, cortadas al perfil parabólico (patrón desde el .scad) | **16** (ver §8 fuerzas) | US$28 |
| A2 | Anillo/aro de borde | Contrachapado 18 mm en segmentos, Ø ext. 1.30 m | 1 juego | US$15 |
| A3 | Cubo central (hub del piso) | Disco de contrachapado 18 mm laminado ×3 (54 mm) | 1 | US$5 |
| A4 | Piel del cuenco (skin) | Contrachapado flexible 3–4 mm (luan/doorskin) o hardboard/masonite, cara lisa | 2–3 hojas | US$25 |
| A5 | **Superficie deslizante** (la que toca el pie) | Opción económica: hardboard sellado con poliuretano + spray de silicona. Opción premium: lámina **HDPE/UHMW 2 mm** o vinílico liso | según opción | US$0–40 |
| A6 | Cola + grapas + tornillos para laminar la piel | Cola de carpintero D3, tornillos 4×20 mm | — | US$10 |
| A7 | Pies antideslizantes / niveladores | Tacos de goma o niveladores M8 | 4–6 | US$8 |

**Subtotal A ≈ US$90–110**

> Alternativa ultra-barata (probada en builds Hackaday/Instructables): forrar el cuenco con **alfombra de pelo corto** y usar **deslizadores de muebles (furniture sliders)** de PTFE en el calzado. Invierte la lógica (alfombra fija + PTFE en el pie) y cuesta ~US$20. Menos duradero pero funcional.

---

## B. Estructura de soporte y base

Aro estructural que sostiene el cuenco a ras de piso y el poste posterior del brazo. Zona del poste = **acero** (soporta el momento del brazo); resto puede ser madera o PVC.

| # | Componente | Material / Especificación | Cant. | Costo aprox. |
|---|---|---|---|---|
| B1 | Marco perimetral inferior | Tubo cuadrado acero 40×40×2 mm **o** viga de pino 45×90 mm | ~5 m | US$30 |
| B2 | **Poste posterior** (mástil del hub) | Tubo cuadrado acero **50×50×3 mm**, alto ~0.35 m sobre el aro | 1 | US$15 |
| B3 | Placa base del poste + cartelas | Platina acero 6 mm + escuadras soldadas/atornilladas | 1 juego | US$12 |
| B4 | Travesaños / refuerzos | Tubo PVC 40 mm (no estructural) o pino | ~3 m | US$10 |
| B5 | Ruedas de traslado (retráctiles) | 2 ruedas industriales 75 mm en el borde trasero (para inclinar y mover) | 2 | US$10 |
| B6 | Tornillería estructural | Pernos M8/M10, tuercas, arandelas, tirafondos | lote | US$15 |
| B7 | **Lastre anti-vuelco** (¡crítico!) | 25–30 kg: arena en cajones del marco, bloques de concreto o pavers, en la mitad trasera (ver §6 fuerzas) | — | US$5 |

**Subtotal B ≈ US$90**

---

## C. Brazo articulado + hub rotatorio + arnés (el "soporte corporal")

Réplica funcional del brazo posterior del Omni One: gira 360° en un hub sobre rodamiento, con dos eslabones y juntas abisagradas (eje horizontal para giro, eje vertical + resorte de gas para agacharse/saltar), rematado en un chaleco/arnés.

| # | Componente | Material / Especificación | Cant. | Costo aprox. |
|---|---|---|---|---|
| C1 | **Rodamiento del hub (giro 360°)** | *Bici:* cazoletas de **pedalier (bottom bracket)** o **buje de rueda** reutilizado; *o* rodamiento tipo **lazy-susan** 150 mm; *o* rodamiento cónico 6008 | 1 | US$8–20 |
| C2 | Eje / husillo del hub | Eje de pedalier de bici **o** perno M16 rectificado + tuercas de leva | 1 | US$8 |
| C3 | Eslabón inferior del brazo | Tubo acero **40×40×3 mm** (M=610 N·m, ver §3 fuerzas), ~0.6 m | 1 | US$12 |
| C4 | Eslabón superior del brazo | Igual, ~0.5 m | 1 | US$8 |
| C5 | **Juntas abisagradas** (2 ejes) | *Bici:* rodamientos de **suspensión/dirección (headset)**; *o* rodamientos 6001 + eje M12; **abrazaderas impresas en 3D** para unir tubos | 2–3 | US$15 |
| C6 | **Resorte de gas (soporte vertical)** | Cilindro **hidroneumático de silla de oficina** (~US$10) *o* amortiguador de portón trasero de auto ~150–250 N; permite agacharse y devuelve suave | 1 | US$10–18 |
| C7 | Tuerca de leva / quick-release | Palanca de **cierre rápido de bici (QR)** para bloquear altura/ángulo del brazo | 1–2 | US$6 |
| C8 | **Chaleco / arnés** | Arnés de escalada acolchado *o* cinturón lumbar de halterofilia + tirantes; placa de anclaje impresa en 3D al brazo | 1 | US$25 |
| C9 | Rótula de conexión brazo↔chaleco | Rótula de dirección de auto (rótula de suspensión) pequeña o junta universal impresa reforzada | 1 | US$10 |
| C10 | Tornillería + bujes | M12/M16, arandelas grasas, bujes de nylon/impresos | lote | US$12 |

**Subtotal C ≈ US$110–130**

> Aquí es donde entran las **piezas de bicicleta e hidráulicas**: el pedalier/buje da el giro de 360° con rodamiento sellado y barato; el headset da las juntas; el QR da el bloqueo tipo "tuerca de leva" del Omni; y el resorte de gas cubre el desplazamiento vertical para agacharse/saltar.

---

## D. Calzado deslizante (overshoes)

Se calzan **sobre** las zapatillas. Suela de baja fricción (negra, deslizante) + sección de agarre (verde, para entrar/salir), tal como el Omni One. Chasis impreso en 3D.

| # | Componente | Material / Especificación | Cant. (par) | Costo aprox. |
|---|---|---|---|---|
| D1 | Chasis del overshoe | **Impreso 3D** (PETG, suela ligeramente curva para casar con el cuenco) | 2 | US$6 (filamento) |
| D2 | Almohadilla deslizante | Disco de **PTFE / UHMW** o deslizador de muebles de PTFE Ø50–60 mm | 2–4 | US$8 |
| D3 | Sección de agarre | Parche de goma/EVA de alta tracción, retráctil o en el talón | 2 | US$5 |
| D4 | Correas de sujeción | Velcro ancho + hebillas *o* **correas de calapié de bici (toe straps)** | 2 juegos | US$8 |
| D5 | Plantilla / soporte del sensor | Alojamiento impreso para el tracker IMU en el empeine/talón | 2 | incl. |

**Subtotal D ≈ US$27**

---

## E. Sensores de pies (foot trackers IMU) — 1 por pie

Electrónica estilo **SlimeVR**: ESP32 + IMU 9-DOF por pie, con sensor de presión de talón (FSR) opcional para detectar la pisada. Alimentado por LiPo. Carcasa impresa.

| # | Componente | Material / Especificación | Cant. | Costo aprox. |
|---|---|---|---|---|
| E1 | Microcontrolador | **ESP32** (WROOM) o ESP32-C3 mini (WiFi/BLE + ESP-NOW) | 2 | US$8 |
| E2 | **IMU 9-DOF** | **MPU-9250** o **ICM-20948** (accel+gyro+magnetómetro) — el mag da rumbo absoluto | 2 | US$10 |
| E3 | Sensor de pisada (opcional) | **FSR** (force-sensitive resistor) 0.5" en el talón, para heel-strike/toe-off | 2 | US$6 |
| E4 | Batería | LiPo 3.7 V 500–1000 mAh | 2 | US$8 |
| E5 | Cargador / protección | Módulo **TP4056** con protección | 2 | US$3 |
| E6 | Interruptor + LED estado | Micro-switch + LED RGB (verde=OK, parpadeo=pairing, como el Omni) | 2 | US$3 |
| E7 | Carcasa impresa 3D | PLA/PETG, clip al overshoe | 2 | incl. |
| E8 | Cableado / JST / resistencias | Divisor del FSR (10k), cables, headers | lote | US$4 |

**Subtotal E ≈ US$42**

---

## F. Electrónica hub / puente a la PC

Un ESP32 receptor recibe ambos pies por ESP-NOW, fusiona el vector de locomoción y se presenta a la PC como **mando USB (HID gamepad)** — así funciona con cualquier juego/SteamVR sin driver propietario.

| # | Componente | Material / Especificación | Cant. | Costo aprox. |
|---|---|---|---|---|
| F1 | MCU receptor con USB nativo | **ESP32-S3** (USB HID nativo) o ESP32 + módulo USB | 1 | US$7 |
| F2 | Carcasa + montaje | Impresa 3D, fija al poste | 1 | incl. |
| F3 | Cable USB a PC | USB-C, 3 m + alargador (alejar antena del ruido USB3) | 1 | US$5 |
| F4 | (Opcional) OLED de diagnóstico | SSD1306 0.96" (estado, batería, vector) | 1 | US$4 |

**Subtotal F ≈ US$16**

---

## G. Consumibles

| # | Componente | Especificación | Costo aprox. |
|---|---|---|---|
| G1 | **Lubricante de silicona** en spray | Equivalente al "EASY-WALK" del Omni; reduce fricción del cuenco | US$8 |
| G2 | Filamento 3D | ~1.5 kg PLA/PETG total (juntas, calzado, carcasas, patrones) | US$30 |
| G3 | Poliuretano/sellador + lija | Para acabado liso del cuenco | US$12 |
| G4 | Grasa para rodamientos | Bici/multiuso | US$5 |

**Subtotal G ≈ US$55**

---

## Resumen de costos

| Subsistema | Costo aprox. |
|---|---|
| A. Cuenco cóncavo | US$90–110 |
| B. Estructura y base | US$90 |
| C. Brazo + hub + arnés | US$110–130 |
| D. Calzado deslizante | US$27 |
| E. Sensores de pies | US$42 |
| F. Electrónica hub | US$16 |
| G. Consumibles | US$55 |
| **TOTAL** | **≈ US$430** (realista US$250–350 rescatando material) |

---

## Piezas impresas en 3D (índice — ver `cad/openomni.scad`)

1. `costilla_patron` — plantilla del perfil parabólico para trazar sobre contrachapado
2. `abrazadera_junta` — abrazaderas de las juntas abisagradas del brazo (×3)
3. `hub_tapa` — tapa/guía del rodamiento del hub rotatorio
4. `overshoe_chasis` — chasis del calzado deslizante (×2, espejado)
5. `sensor_carcasa` — carcasa del tracker IMU (×2)
6. `hub_carcasa` — carcasa de la electrónica receptora
7. `ancla_chaleco` — placa de anclaje brazo↔arnés

## Herramientas necesarias

Sierra de calar (jigsaw), taladro, atornillador, llaves, **impresora 3D** (≥200×200 mm), soldadora (si se usa acero; opcional si todo es madera+pernos), lijadora, pistola de silicona/cola.

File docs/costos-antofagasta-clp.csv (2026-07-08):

OpenOmni - Costos Antofagasta (CLP)
Subsistema | Componente | Cant. | Precio max | Subtotal max | Precio ECO | Subtotal ECO | Como bajar de precio
Cuenco y estructura (madera)
 | Terciado estructural 18mm (1.22x2.44m) | 3 | 38000 | 114000 | 15000 | 45000 | OSB / pallet reciclado
 | Pino 2x4" radiales | 8 | 4500 | 36000 | 1500 | 12000 | pallet / rescatado
 | Pino 2x12" bloque central | 1 | 14000 | 14000 | 6000 | 6000 | madera rescatada
 | Tornillos estructurales 8x80mm | 1 | 16000 | 16000 | 10000 | 10000 | menos cantidad
 | Tornillos madera 4x40mm | 1 | 9000 | 9000 | 5000 | 5000
 | Adhesivo maderas D3 | 1 | 8000 | 8000 | 6000 | 6000
 | Superficie deslizante | 1 | 42000 | 42000 | 12000 | 12000 | alfombra + deslizadores (DIY) en vez de HDPE
 | Lubricante silicona spray | 1 | 8000 | 8000 | 6000 | 6000
 |  |  | Subtotal | 247000 |  | 102000
Giro (anillo/collar) + fierros
 | Rodamiento giratorio del collar | 1 | 30000 | 30000 | 12000 | 12000 | lazy-susan barato / rueda auto rescatada
 | Ruedas / rodillos | 4 | 6000 | 24000 | 2000 | 8000 | rescatadas
 | Tubo cuadrado 40x40x3mm (6m) | 1 | 26000 | 26000 | 12000 | 12000 | fierro usado
 | Tubo cuadrado 50x50x3mm (2m) | 1 | 13000 | 13000 | 7000 | 7000 | fierro usado
 | Rodamientos 6008 (juntas) | 2 | 5000 | 10000 | 2000 | 4000 | de bicicleta rescatados
 | Pernos M10/M12 8.8 + tuercas | 1 | 16000 | 16000 | 10000 | 10000
 | Pin acero M10 (codo) + pletinas | 1 | 8000 | 8000 | 5000 | 5000
 | Cierre rapido (QR) bici | 1 | 7000 | 7000 | 3000 | 3000 | rescatado
 |  |  | Subtotal | 134000 |  | 61000
Hidraulica (resorte de gas)
 | Resorte a gas 300-400N | 1 | 16000 | 16000 | 5000 | 5000 | cilindro de silla de oficina rescatado
 | Terminales rotula / clevis M8 | 2 | 4500 | 9000 | 2500 | 5000
 |  |  | Subtotal | 25000 |  | 10000
Arnes y calzado
 | Cinturon lumbar / arnes | 1 | 25000 | 25000 | 10000 | 10000 | arnes que ya tengas
 | Deslizadores PTFE/UHMW | 4 | 3000 | 12000 | 1500 | 6000 | deslizadores de muebles basicos
 | Correas velcro + hebillas | 1 | 6000 | 6000 | 3000 | 3000
 | Filamento PETG 1kg | 1 | 20000 | 20000 | 12000 | 12000 | PLA / menos filamento
 |  |  | Subtotal | 63000 |  | 31000
Electronica (sensores + hub)
 | ESP32-C3 (tracker) | 2 | 6000 | 12000 | 4000 | 8000 | ESP32 generico
 | IMU MPU-9250 | 2 | 7000 | 14000 | 3000 | 6000 | MPU6050 (6 ejes)
 | FSR sensor de fuerza | 2 | 6000 | 12000 | 0 | 0 | omitir: deteccion solo por IMU
 | LiPo + TP4056 | 2 | 7000 | 14000 | 5000 | 10000
 | ESP32-S3 (hub) | 1 | 10000 | 10000 | 8000 | 8000
 | Cables, JST, headers | 1 | 8000 | 8000 | 5000 | 5000
 |  |  | Subtotal | 70000 |  | 37000
Varios / consumibles
 | Poliuretano/sellador + lija | 1 | 13000 | 13000 | 8000 | 8000
 | Grasa rodamientos | 1 | 5000 | 5000 | 3000 | 3000
 | Imprevistos / envios (~10%) | 1 | 55000 | 55000 | 30000 | 30000 | menos colchon
 |  |  | Subtotal | 73000 |  | 41000
 |  |  | TOTAL | 612000 |  | 282000

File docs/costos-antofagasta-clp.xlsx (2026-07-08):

OpenOmni - Costos (Antofagasta, Chile) - CLP
Escenario MAXIMO vs ECONOMICO (rescatando/sustituyendo). Edita cant/precios y recalcula.
Subsistema | Componente | Cant. | Precio max | Subtotal max | Precio ECO | Subtotal ECO | Como bajar de precio
Cuenco y estructura (madera)
 | Terciado estructural 18mm (1.22x2.44m) | 3 | 38000 CLP |  | 15000 CLP |  | OSB / pallet reciclado
 | Pino 2x4" radiales | 8 | 4500 CLP |  | 1500 CLP |  | pallet / rescatado
 | Pino 2x12" bloque central | 1 | 14000 CLP |  | 6000 CLP |  | madera rescatada
 | Tornillos estructurales 8x80mm | 1 | 16000 CLP |  | 10000 CLP |  | menos cantidad
 | Tornillos madera 4x40mm | 1 | 9000 CLP |  | 5000 CLP
 | Adhesivo maderas D3 | 1 | 8000 CLP |  | 6000 CLP
 | Superficie deslizante | 1 | 42000 CLP |  | 12000 CLP |  | alfombra + deslizadores (DIY) en vez de HDPE
 | Lubricante silicona spray | 1 | 8000 CLP |  | 6000 CLP
 |  | Subtotal
Giro (anillo/collar) + fierros
 | Rodamiento giratorio del collar | 1 | 30000 CLP |  | 12000 CLP |  | lazy-susan barato / rueda auto rescatada
 | Ruedas / rodillos | 4 | 6000 CLP |  | 2000 CLP |  | rescatadas
 | Tubo cuadrado 40x40x3mm (6m) | 1 | 26000 CLP |  | 12000 CLP |  | fierro usado
 | Tubo cuadrado 50x50x3mm (2m) | 1 | 13000 CLP |  | 7000 CLP |  | fierro usado
 | Rodamientos 6008 (juntas) | 2 | 5000 CLP |  | 2000 CLP |  | de bicicleta rescatados
 | Pernos M10/M12 8.8 + tuercas | 1 | 16000 CLP |  | 10000 CLP
 | Pin acero M10 (codo) + pletinas | 1 | 8000 CLP |  | 5000 CLP
 | Cierre rapido (QR) bici | 1 | 7000 CLP |  | 3000 CLP |  | rescatado
 |  | Subtotal
Hidraulica (resorte de gas)
 | Resorte a gas 300-400N | 1 | 16000 CLP |  | 5000 CLP |  | cilindro de silla de oficina rescatado
 | Terminales rotula / clevis M8 | 2 | 4500 CLP |  | 2500 CLP
 |  | Subtotal
Arnes y calzado
 | Cinturon lumbar / arnes | 1 | 25000 CLP |  | 10000 CLP |  | arnes que ya tengas
 | Deslizadores PTFE/UHMW | 4 | 3000 CLP |  | 1500 CLP |  | deslizadores de muebles basicos
 | Correas velcro + hebillas | 1 | 6000 CLP |  | 3000 CLP
 | Filamento PETG 1kg | 1 | 20000 CLP |  | 12000 CLP |  | PLA / menos filamento
 |  | Subtotal
Electronica (sensores + hub)
 | ESP32-C3 (tracker) | 2 | 6000 CLP |  | 4000 CLP |  | ESP32 generico
 | IMU MPU-9250 | 2 | 7000 CLP |  | 3000 CLP |  | MPU6050 (6 ejes)
 | FSR sensor de fuerza | 2 | 6000 CLP |  | 0 CLP |  | omitir: deteccion solo por IMU
 | LiPo + TP4056 | 2 | 7000 CLP |  | 5000 CLP
 | ESP32-S3 (hub) | 1 | 10000 CLP |  | 8000 CLP
 | Cables, JST, headers | 1 | 8000 CLP |  | 5000 CLP
 |  | Subtotal
Varios / consumibles
 | Poliuretano/sellador + lija | 1 | 13000 CLP |  | 8000 CLP
 | Grasa rodamientos | 1 | 5000 CLP |  | 3000 CLP
 | Imprevistos / envios (~10%) | 1 | 55000 CLP |  | 30000 CLP |  | menos colchon
 |  | Subtotal
 |  | TOTAL

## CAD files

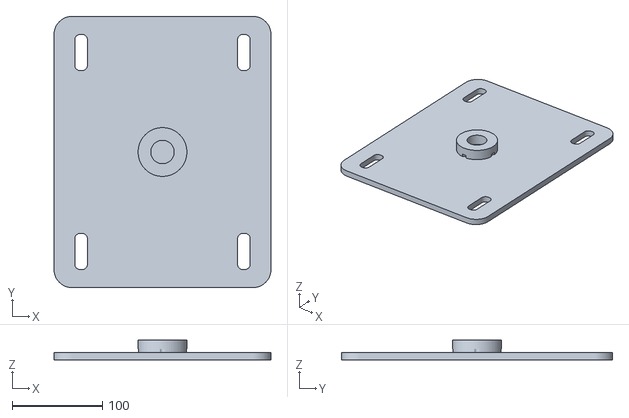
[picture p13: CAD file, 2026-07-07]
cad/j_vest.stl
240.0 x 300.0 x 22.0

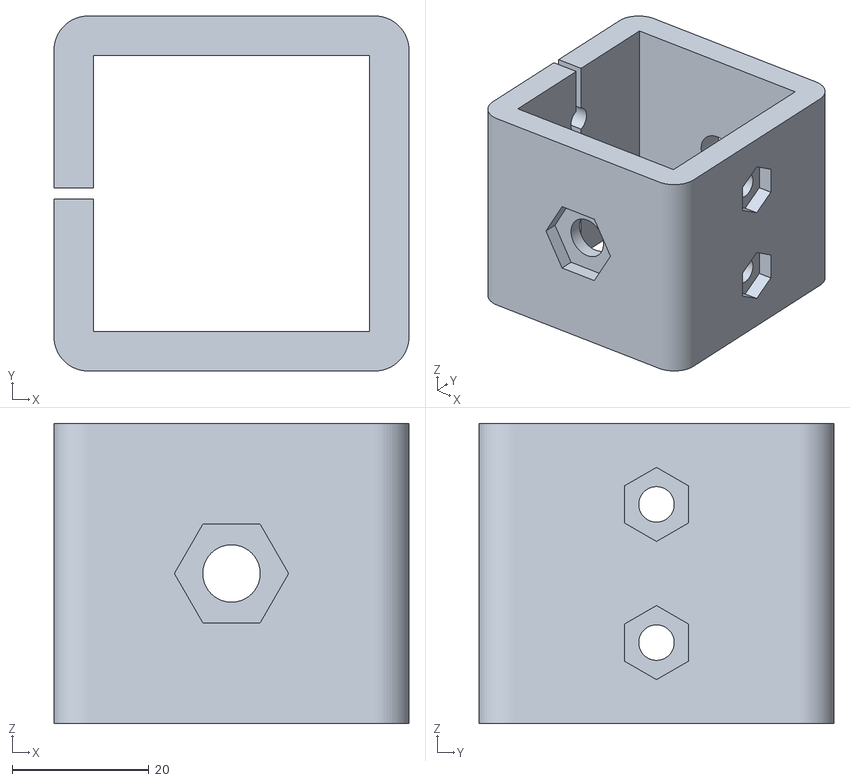
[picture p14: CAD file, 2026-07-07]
cad/j_clamp.stl
52.0 x 52.0 x 44.0

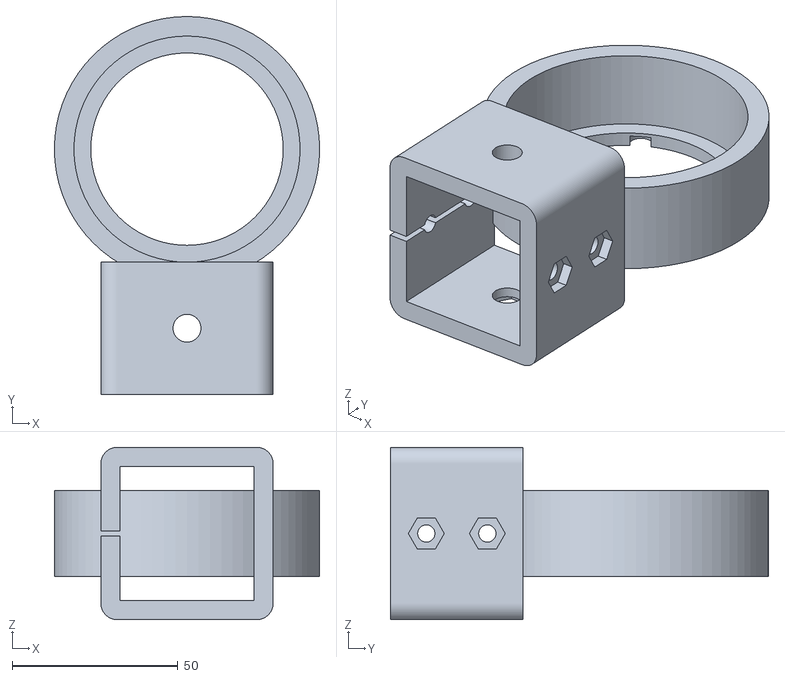
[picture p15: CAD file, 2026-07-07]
cad/j_hub.stl
80.0 x 114.0 x 52.0

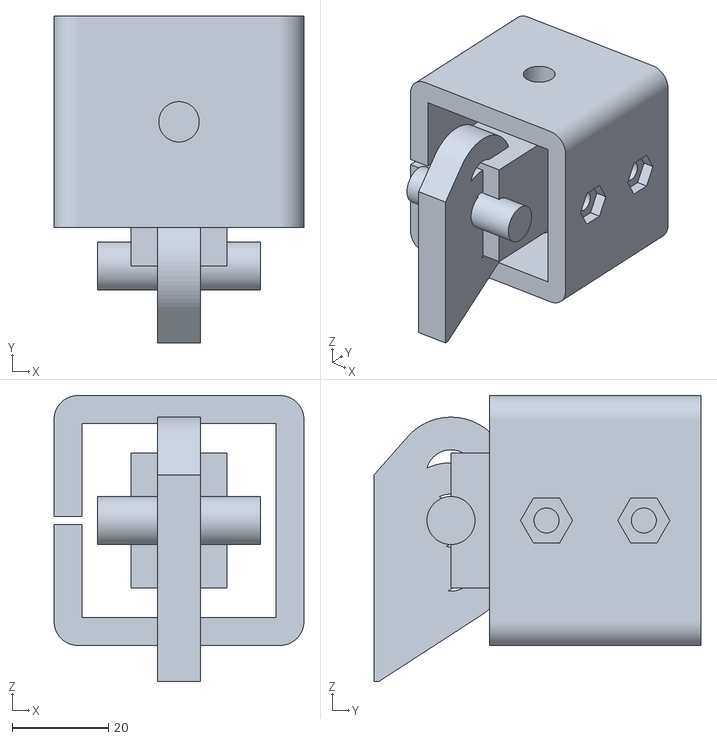
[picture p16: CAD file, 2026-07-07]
cad/j_elbow.stl
52.0 x 68.0 x 59.5

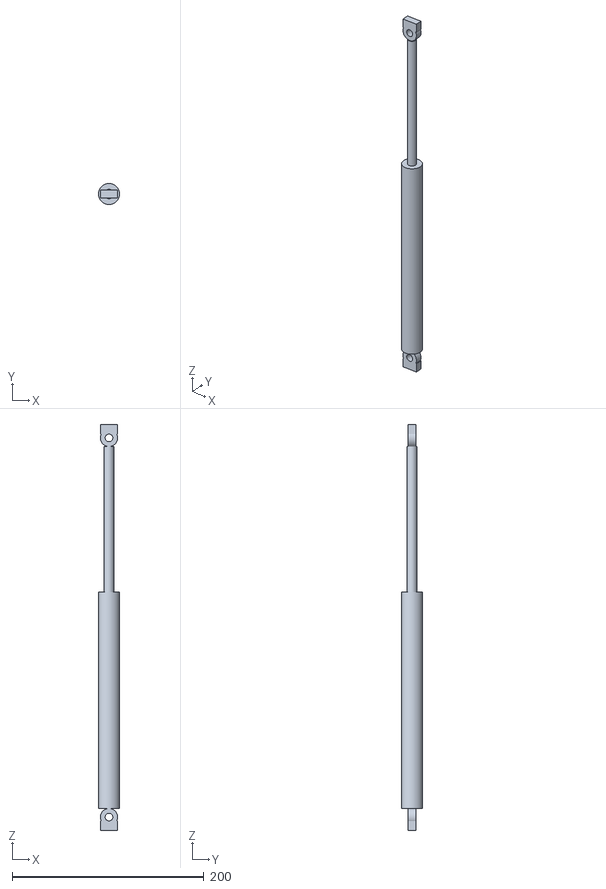
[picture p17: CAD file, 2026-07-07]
cad/gas_strut.stl
22.0 x 22.0 x 424.0

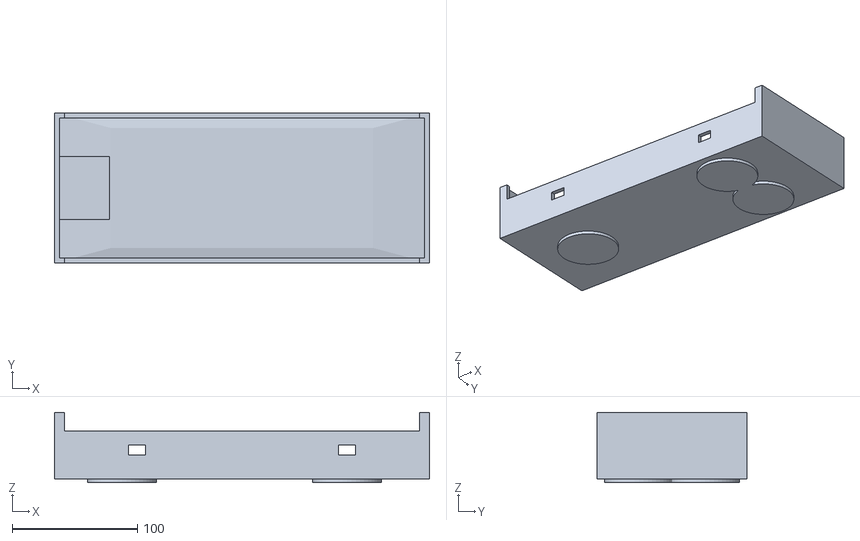
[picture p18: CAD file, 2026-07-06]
cad/overshoe.stl
300.0 x 120.0 x 56.0

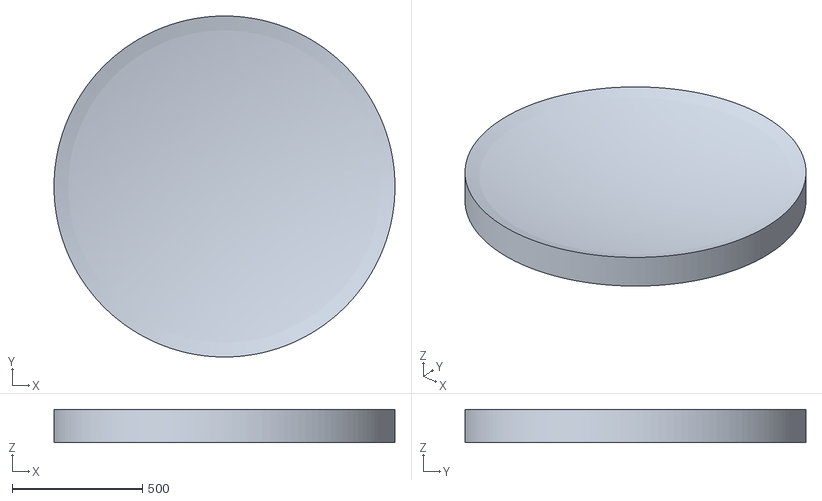
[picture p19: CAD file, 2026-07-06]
cad/bowl.stl
1310.0 x 1310.0 x 127.3

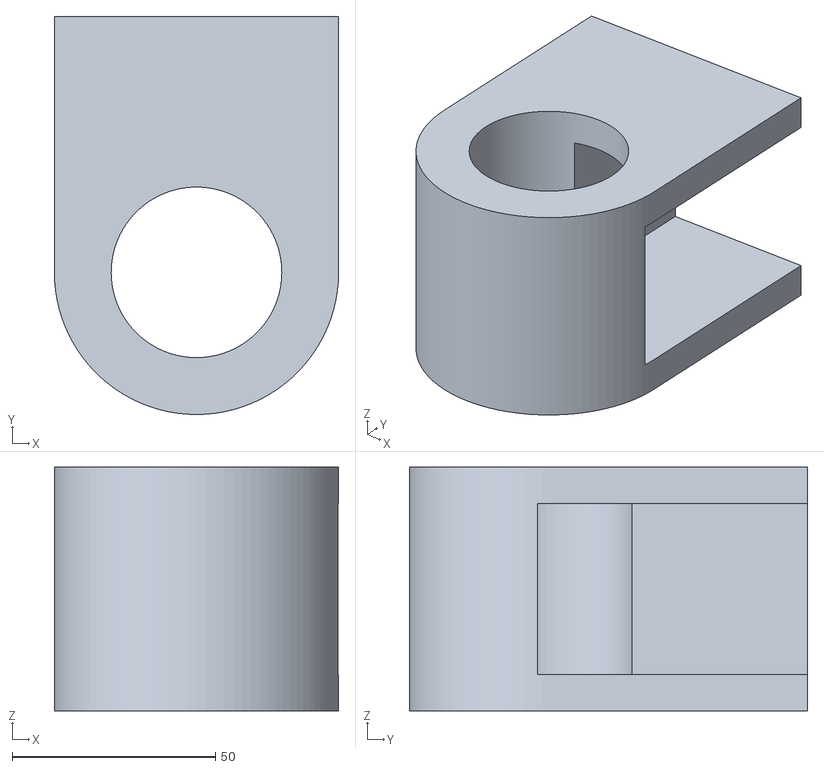
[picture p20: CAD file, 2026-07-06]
cad/arm_hub.stl
70.0 x 98.0 x 60.0

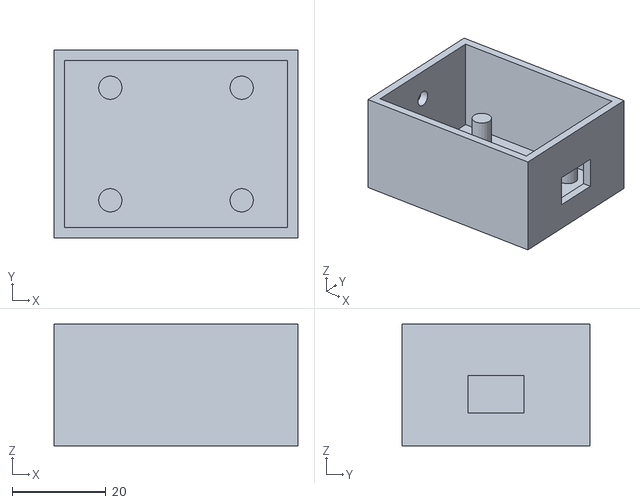
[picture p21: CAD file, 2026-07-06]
cad/sensor_case.stl
52.0 x 40.0 x 26.0

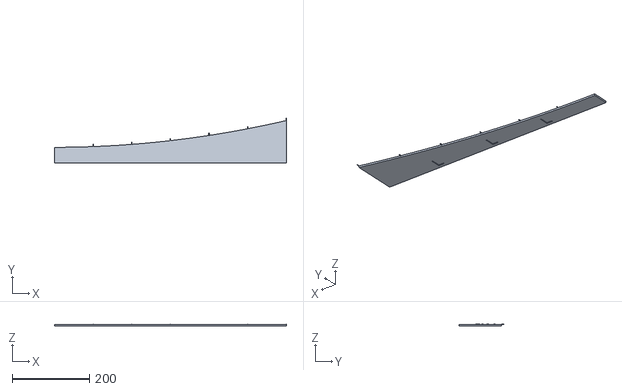
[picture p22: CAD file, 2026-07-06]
cad/rib_template.stl
600.5 x 115.3 x 4.50

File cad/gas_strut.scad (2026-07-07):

// ============================================================
//  OpenOmni - Resorte de gas (gas strut) PARAMÉTRICO
//  Modela el muelle neumático real + un CORTE que explica
//  cómo funciona por dentro. Unidades: mm.
//
//  part:
//   "assembly"  -> strut completo, extendido
//   "section"   -> MEDIO CORTE que revela el interior (educativo)
//   "compressed"-> corte con el vástago comprimido (gas comprimido)
//   "mount"     -> abrazadera impresa + ojal de acero (cómo se fija)
// ============================================================
part = "section";

// ---------- parámetros ----------
Lb      = 220;   // largo del cuerpo (tubo)
OD      = 24;    // diámetro exterior del cuerpo
wall    = 1.5;   // pared del tubo
ID      = OD-2*wall;
rod_d   = 10;    // diámetro del vástago
stroke  = 120;   // carrera del vástago
eye_od  = 18;    // ojal de montaje (exterior)
eye_bore= 8;     // perno M8
eye_th  = 8;     // espesor del ojal
$fn     = 80;

ext = (part=="compressed") ? 0.25 : (part=="section" ? 0.55 : 1.0);

// ------------------------------------------------------------
module eye(){                      // ojal de montaje con bore para perno
    difference(){
        union(){
            rotate([90,0,0]) cylinder(d=eye_od,h=eye_th,center=true);
            translate([0,0,-eye_od/2]) cube([eye_od,eye_th,eye_od/2+1],center=true);
        }
        rotate([90,0,0]) cylinder(d=eye_bore,h=eye_th+2,center=true);
    }
}

module strut(ext=1, cut=false){
    rod_out  = 40 + ext*stroke;              // cuánto sobresale el vástago
    pistonZ  = 20 + (Lb-55)*ext;             // pistón: alto si extendido, bajo si comprimido
    difference(){
        union(){
            // --- cuerpo: tubo de acero (hueco) + tapa inferior ---
            color("silver"){
                difference(){ cylinder(d=OD,h=Lb); translate([0,0,4]) cylinder(d=ID,h=Lb); }
                translate([0,0,-6]) cylinder(d=OD,h=8);
                translate([0,0,-6-eye_od/2]) eye();                 // ojal del cuerpo
            }
            // --- INTERIOR: como BLOQUES en la mitad y<0 (cara plana en y=0, sin z-fighting) ---
            gd = ID-0.8;                                   // ancho de las cámaras
            // gas N2 a presión (bajo el pistón)
            color([0.25,0.55,1.0]) translate([0,-gd/4,(4+pistonZ)/2]) cube([gd, gd/2, pistonZ-4], center=true);
            // pistón (émbolo con sello)
            color("black") translate([0,-gd/4,pistonZ+4.5]) cube([gd, gd/2, 9], center=true);
            // aceite (amortiguación, sobre el pistón)
            color([0.95,0.55,0.10]) translate([0,-gd/4,(pistonZ+9+Lb-12)/2]) cube([gd, gd/2, Lb-12-(pistonZ+9)], center=true);
            // orificio de paso del pistón (aceite -> amortiguación viscosa)
            color("yellow") translate([rod_d/2+2,-gd/4,pistonZ+4.5]) cube([2,gd/2,9], center=true);
            // --- vástago (unido al pistón, sale por arriba) ---
            color("gainsboro"){
                translate([0,-gd/4,(pistonZ+9+Lb)/2]) cube([rod_d, gd/2, Lb-(pistonZ+9)], center=true); // tramo interno
                translate([0,0,Lb]) cylinder(d=rod_d, h=rod_out);               // tramo externo
                translate([0,0,Lb+rod_out+eye_od/2]) rotate([0,180,0]) eye();   // ojal del vástago
            }
            // guía/sello superior del cuerpo
            color("dimgray") translate([0,0,Lb-12]) cylinder(d=OD-0.5, h=12);
        }
        if(cut) translate([0,OD,Lb/2]) cube([OD*3, OD*2, Lb*4], center=true);   // medio corte (quita y>0)
    }
}

// ---------- abrazadera impresa + ojal de acero (cómo se fija al brazo) ----------
module mount(){
    tube=32;               // tubo del brazo Ø32
    color("orange")
    difference(){
        union(){ cube([tube+16, tube+16, 22], center=true);
                 translate([0,-(tube+16)/2-3,0]) cube([tube+16,8,22],center=true); }
        cylinder(d=tube+0.4, h=30, center=true);                       // socket del tubo (+0.4 tol. FDM)
        cube([1.4, tube+24, 24], center=true);                         // ranura del split-clamp
        for(z=[-7,7]) translate([tube/2+5,-tube/2-3,z]) rotate([0,90,0]) cylinder(d=5.2,h=24,center=true); // pernos clamp M5
        rotate([90,0,0]) cylinder(d=8.2, h=tube+40, center=true);      // PERNO M8 pasante (el que aguanta)
    }
    color("dimgray") eye();                                            // ojal de acero del strut en el perno
}

// ---------- selector ----------
if(part=="assembly")        strut(1,false);
else if(part=="section")    strut(ext,true);
else if(part=="compressed") strut(ext,true);
else if(part=="mount")      mount();

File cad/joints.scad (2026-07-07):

// ============================================================
//  OpenOmni - Juntas impresas en 3D (realistas)
//  Clamps partidos, junta de codo (horquilla + pin de acero),
//  placa de mochila y clamp del hub. Unidades: mm.
//
//  Filosofia: el PLASTICO solo posiciona/abraza; la carga la
//  toma el ACERO (pernos pasantes / pin de la bisagra).
//
//  part: "elbow" | "clamp" | "vest" | "hub" | "all"
// ============================================================
part = "elbow";

// ---------- parametros globales ----------
tol   = 0.40;   // holgura de socket para FDM (deslizante y luego se aprieta)
wall  = 6;      // pared portante minima
$fn   = 72;

M5 = 5.2; M6 = 6.4; M8 = 8.4; M10 = 10.4;   // agujeros pasantes (broca + holgura)
NUT5 = 9.4; NUT6 = 11.5; NUT8 = 14.5;        // entrecaras de tuerca (pocket hex)

module bolt_hole(d, l)   { cylinder(d=d, h=l, center=true); }
module nut_pocket(af, h) { cylinder(d=af/cos(30), h=h, $fn=6); }
module heatset_boss(){ // inserto roscado M5 (Ø4.6 x 8)
    difference(){ cylinder(d=8, h=9); translate([0,0,2]) cylinder(d=4.6, h=8); }
}
// bloque de esquinas redondeadas (agradable de imprimir)
module rbox(x,y,z,r=4){ hull() for(a=[-1,1],b=[-1,1])
    translate([a*(x/2-r), b*(y/2-r), 0]) cylinder(r=r, h=z); }

// ============================================================
//  1) CLAMP PARTIDO para tubo cuadrado (el caballo de batalla)
//     socket con tolerancia + ranura + 2 pernos + tuercas + perno pasante
// ============================================================
module split_clamp_sq(tube=40, len=44, boltM=M5, nutAF=NUT5, thru=true, thruM=M8){
    o = tube + 2*wall;
    difference(){
        rbox(o, o, len, 5);
        // socket del tubo (tolerancia FDM)
        translate([0,0,-1]) linear_extrude(len+2) square(tube+tol, center=true);
        // ranura del split (permite apretar)
        translate([-o, -0.8, -1]) cube([o, 1.6, len+2]);
        // 2 pernos de apriete que cruzan la ranura
        for(z=[len*0.27, len*0.73]) translate([0,0,z]) rotate([0,90,0]){
            bolt_hole(boltM, o+2);
            translate([0,0, o/2-3]) nut_pocket(nutAF, 6);       // tuerca embebida (lado +X)
        }
        // perno de ACERO pasante que atraviesa el tubo (toma el cortante)
        if(thru) translate([0,0,len/2]) rotate([90,0,0]){
            bolt_hole(thruM, o+2);
            translate([0,0, o/2-3]) nut_pocket(NUT8, 6);
        }
    }
}

// ============================================================
//  2) CODO ARTICULADO: horquilla (fork) + hoja (blade) + PIN de acero
//     el pin M10 en doble cortante toma el momento; el plastico abraza
// ============================================================
pin   = M10;
earR  = 12;      // radio de la oreja alrededor del pin
earT  = 9;       // espesor de cada oreja
bladeGap = earT + 2*0.5;  // hueco de la horquilla para la hoja

module ear(bore){ difference(){
    hull(){ cylinder(r=earR, h=earT); translate([0,-earR-4,0]) cube([2*earR,1,earT]); }
    translate([0,0,-1]) cylinder(d=bore, h=earT+2);
}}

// pieza superior: clamp del tubo + HORQUILLA (2 orejas)
module elbow_fork(){
    color("darkorange"){
        translate([0,0,0]) rotate([90,0,0]) split_clamp_sq(40, 44, thru=true);
        // brazo que baja a las orejas
        translate([-10,-52,-(bladeGap/2+earT)]) cube([20,52,bladeGap+2*earT]);
        for(s=[-1,1]) translate([0,-52,s*(bladeGap/2+earT/2)])
            rotate([0,90,0]) translate([0,0,-earT/2]) ear(pin);
    }
}
// pieza inferior: clamp del tubo + HOJA (1 oreja centrada)
module elbow_blade(){
    color("orange"){
        translate([0,0,0]) rotate([90,0,0]) split_clamp_sq(40, 44, thru=true);
        translate([-8,-52,-earT/2]) cube([16,52,earT]);
        translate([0,-52,0]) rotate([0,90,0]) translate([0,0,-earT/2]) ear(pin+0.6); // buje/holgura
    }
}
// pin de acero + arandelas (referencia)
module elbow_pin(){ color("silver"){
    rotate([0,90,0]) cylinder(d=10, h=bladeGap+2*earT+6, center=true);
}}
module elbow(){
    elbow_blade();
    translate([0,0,0]) elbow_fork();
    translate([0,-52,0]) elbow_pin();
}

// ============================================================
//  3) PLACA DE LA MOCHILA (chaleco): baja carga, se puede imprimir
//     placa curva + ranuras de correa + rotula para el brazo
// ============================================================
module vest_plate(){
    w=240; h=300; t=8;
    color("orange") difference(){
        // placa ligeramente curva (se adapta a la espalda)
        intersection(){
            translate([0,0,-t]) rbox(w,h,t,20);
            translate([0,0,-260]) cylinder(r=280, h=300);   // curvatura suave
        }
        // ranuras para correas (4)
        for(y=[-h/2+40, h/2-40]) for(x=[-w/2+30, w/2-30])
            translate([x,y,-t-1]) rbox(14, 40, t+2, 6);
        // 4 agujeros para el anclaje de la rotula del brazo (centro)
        for(a=[0,90,180,270]) rotate([0,0,a]) translate([28,0,-t-1]) bolt_hole(M6, t+2);
    }
    // boss central donde va la rotula/junta del brazo
    color("darkorange") translate([0,0,-t]) difference(){
        cylinder(d=54, h=22); translate([0,0,4]) cylinder(d=26, h=20); // alojamiento rotula
        for(a=[0,90,180,270]) rotate([0,0,a]) translate([28,0,-1]) bolt_hole(M6,26);
    }
}

// ============================================================
//  4) CLAMP DEL HUB: abraza el tubo radial y aloja el bearing central
// ============================================================
module hub_clamp(){
    brgOD=68;   // OD del rodamiento (ej. 6013 / rueda remolque) -> ajustar
    color("orange") difference(){
        union(){
            cylinder(d=brgOD+2*wall, h=26);
            translate([0,-(brgOD/2+wall)+6,13]) rotate([90,0,0]) split_clamp_sq(40,40,thru=true);
        }
        translate([0,0,4]) cylinder(d=brgOD+0.2, h=26);   // asiento del rodamiento (press-fit)
        translate([0,0,-1]) cylinder(d=brgOD-10, h=6);    // hombro de apoyo
        // agujeros de brida (M6) para atornillar al carro
        for(a=[0:60:359]) rotate([0,0,a]) translate([brgOD/2-4,0,-1]) bolt_hole(M6,8);
    }
}

// ---------- selector ----------
if(part=="elbow")      elbow();
else if(part=="clamp") split_clamp_sq();
else if(part=="vest")  vest_plate();
else if(part=="hub")   hub_clamp();
else if(part=="all"){
    elbow();
    translate([120,0,0]) split_clamp_sq();
    translate([-120,0,0]) hub_clamp();
    translate([0,320,0]) scale(0.6) vest_plate();
}

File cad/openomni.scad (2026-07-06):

// ============================================================
//  OpenOmni  -  Treadmill omnidireccional pasiva DIY
//  Modelo parametrico inspirado en el Virtuix Omni One
//  Unidades: milimetros
//  OpenSCAD 2021.01+
// ============================================================
//  Que renderizar:
//   "assembly"     -> conjunto completo (vista)
//   "bowl"         -> cuenco solido (referencia de construccion)
//   "rib_template" -> plantilla de UNA costilla para trazar/cortar
//   "overshoe"     -> calzado deslizante (imprimible)
//   "sensor_case"  -> carcasa del tracker IMU (imprimible)
//   "arm_hub"      -> abrazadera/hub del brazo (imprimible)
part = "assembly";

// ---------- Parametros globales del cuenco ----------
R          = 600;   // radio util del cuenco (mm)
edge_angle = 13;    // pendiente en el borde (grados)
k          = tan(edge_angle) / (2 * R);   // z = k * r^2
rim_w      = 55;    // ancho del aro de borde
base_h     = 40;    // espesor de la base bajo el centro
n_ribs     = 16;    // costillas radiales (ver analisis de fuerzas)
skin_t     = 6;     // piel (luan 3 + hardboard 3)

function zbowl(r) = k * r * r;               // altura de la parabola
zR = zbowl(R);                               // profundidad del borde (~69 mm)

$fn = 96;

// ============================================================
//  CUENCO
// ============================================================
module bowl_solid() {
    steps = 48;
    top = [ for (i=[0:steps]) let(r = R*i/steps) [r, zbowl(r)] ];
    profile = concat(
        top,
        [ [R+rim_w, zR+18],            // labio exterior del aro
          [R+rim_w, -base_h],          // baja al fondo de la base
          [0,       -base_h] ]         // vuelve al centro
    );
    color("burlywood")
        rotate_extrude($fn=140) polygon(profile);
}

// Perfil 2D de UNA costilla (seccion radial): arriba parabola, abajo plano
module rib_profile() {
    steps = 40;
    top = [ for (i=[0:steps]) let(r = R*i/steps) [r, zbowl(r)] ];
    polygon( concat(top, [ [R, -base_h], [0, -base_h] ]) );
}

// Costillas de madera dispuestas radialmente (vista de construccion)
module ribs() {
    rib_t = 15; // espesor del contrachapado
    color("peru")
    for (a = [0 : 360/n_ribs : 359.9])
        rotate([0,0,a])
            translate([0,-rib_t/2,0])
                rotate([90,0,0])              // parar la costilla vertical
                    rotate([0,-90,0])
                        linear_extrude(rib_t)
                            rib_profile();
}

// Plantilla imprimible/trazable de una costilla, con ranuras de ensamble
module rib_template() {
    slot_w = 15; slot_d = base_h*0.6;
    difference() {
        linear_extrude(4) rib_profile();
        // ranuras cada 150 mm para media-madera con anillos concentricos
        for (r = [150 : 150 : R-60])
            translate([r, -base_h/2, -1])
                cube([slot_w, slot_d, 6], center=true);
    }
    // marcas de radio grabadas
    for (r = [100:100:R])
        translate([r, zbowl(r)+3, 4])
            color("black") cube([1, 6, 1], center=true);
}

// ============================================================
//  ESTRUCTURA / BASE
// ============================================================
module square_ring(rad, sec=40) {
    rotate_extrude($fn=120)
        translate([rad,0,0]) square([sec,sec], center=true);
}

module base_frame() {
    color("dimgray") {
        // aro estructural bajo el borde del cuenco
        translate([0,0,-base_h]) square_ring(R+rim_w-20, 40);
        // largueros cruzados
        for (a=[0,90])
            rotate([0,0,a])
                translate([0,0,-base_h])
                    cube([2*(R+rim_w), 40, 40], center=true);
    }
}

// Poste trasero (mastil) que sostiene el hub rotatorio
module rear_post() {
    post = 50; H = 350;
    color("gray")
    translate([R+rim_w-10, 0, -base_h])
        cube([post, post, H+base_h]);
}

// Lastre anti-vuelco (cajones de arena/concreto en la mitad trasera)
module ballast() {
    color("saddlebrown", 0.6)
    translate([R*0.55, -R*0.5, -base_h+5])
        cube([R*0.5, R, 30]);
}

// ============================================================
//  HUB ROTATORIO + BRAZO ARTICULADO
// ============================================================
// Abrazadera/hub imprimible que abraza dos tubos (rodamiento de bici dentro)
module arm_hub() {
    od = 70; id = 42; h = 60; // id = OD del rodamiento/pedalier
    difference() {
        union() {
            cylinder(d=od, h=h);
            translate([-od/2,0,0]) cube([od, od*0.9, h]); // brazo de union
        }
        translate([0,0,-1]) cylinder(d=id, h=h+2);       // alojamiento rodamiento
        // agujero para el tubo del eslabon (40x40)
        translate([od*0.2, od*0.45, h/2]) rotate([90,0,0])
            cube([42,42,od], center=true);
        // tornillos de fijacion
        for (z=[15,45]) translate([0,od*0.6,z]) rotate([90,0,0]) cylinder(d=6,h=30,center=true);
    }
}

// Brazo articulado completo (vista de conjunto)
module arm_assembly() {
    hub_top = 350;
    // hub sobre el poste
    color("orange")
        translate([R+rim_w+15, 0, hub_top-base_h]) rotate([0,0,0]) cylinder(d=70,h=70);
    // eslabon inferior (40x40x3) subiendo y hacia adelante
    color("silver")
        translate([R+rim_w+15, -20, hub_top])
            rotate([0,-35,0]) cube([40,40,650]);
    // junta abisagrada
    color("red")
        translate([R+rim_w-370, 0, hub_top+520]) rotate([90,0,0]) cylinder(d=45,h=50,center=true);
    // eslabon superior hacia el chaleco
    color("silver")
        translate([R+rim_w-380, -20, hub_top+520])
            rotate([0,-70,0]) cube([40,40,520]);
    // placa del chaleco
    vest_plate();
    // gas strut (resorte de gas) esquematico
    color("black")
        translate([R+rim_w-100, 0, hub_top+120])
            rotate([0,-52,0]) cylinder(d=20,h=430);
}

module vest_plate() {
    color("navy")
    translate([50, 0, 1050])
        rotate([0,15,0])
            difference() {
                cube([30, 360, 260], center=true);
                cube([40, 260, 160], center=true); // hueco ergonomico
            }
}

// ============================================================
//  CALZADO DESLIZANTE (imprimible, PETG)
// ============================================================
module overshoe() {
    L=300; W=120; wall=4; base=6;
    difference() {
        union() {
            // suela con ligero rocker
            hull() {
                translate([0,0,0])      cube([L,W,base], center=true);
                translate([0,0,3])      cube([L*0.7,W*0.8,base], center=true);
            }
            // paredes laterales bajas para envolver la zapatilla
            difference() {
                translate([0,0,25]) cube([L,W,50], center=true);
                translate([0,0,32]) cube([L-2*wall,W-2*wall,60], center=true);
                translate([0,0,55]) cube([L-2*wall*2,W+10,40], center=true); // abre arriba
            }
        }
        // ranuras para correas
        for (x=[-L*0.28, L*0.28])
            translate([x,0,20]) cube([14,W+10,8], center=true);
    }
    // almohadillas deslizantes PTFE/UHMW (3 puntos)
    color("black")
    for (p = [[-L*0.32,0],[L*0.28,-W*0.22],[L*0.28,W*0.22]])
        translate([p[0],p[1],-base/2-3]) cylinder(d=55,h=6,$fn=48);
    // pod del sensor en el talon
    color("dimgray")
        translate([-L*0.42,0,15]) cube([40,50,30], center=true);
}

// ============================================================
//  CARCASA DEL SENSOR IMU (imprimible)
// ============================================================
module sensor_case() {
    W=40; L=52; H=26; wall=2.2;
    difference() {
        cube([L,W,H], center=true);
        translate([0,0,wall]) cube([L-2*wall, W-2*wall, H], center=true);
        // ranura USB-C / carga
        translate([L/2, 0, -2]) cube([6,12,8], center=true);
        // LED de estado
        translate([-L/2, 0, 5]) rotate([0,90,0]) cylinder(d=4,h=6,center=true,$fn=24);
    }
    // postes para ESP32
    for (x=[-14,14],y=[-12,12])
        translate([x,y,-H/2+wall]) cylinder(d=5,h=8,$fn=20);
}

// ============================================================
//  CONJUNTO
// ============================================================
module assembly() {
    bowl_solid();
    ribs();
    base_frame();
    rear_post();
    ballast();
    arm_assembly();
    // usuario esquematico (referencia de escala 1.75 m)
    color("lightblue",0.22)
        translate([-40,0,zbowl(0)]) {
            cylinder(d=220,h=820);                 // torso
            translate([0,0,820]) cylinder(d=150,h=150); // cuello
            translate([0,0,1010]) sphere(d=170);   // cabeza
            for (s=[-70,70]) translate([s,0,-40]) cylinder(d=90,h=40); // piernas
        }
    // calzado colocado en el cuenco
    translate([-120,-140, zbowl(150)+8]) scale(0.9) overshoe();
    translate([-120, 140, zbowl(150)+8]) scale(0.9) overshoe();
}
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

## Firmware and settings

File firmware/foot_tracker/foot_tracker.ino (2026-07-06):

// ============================================================
//  OpenOmni - FOOT TRACKER  (uno por pie)
//  MCU : ESP32 / ESP32-C3
//  IMU : MPU-9250 / MPU-6500 (I2C)   +  FSR de talon (ADC)
//  Salida: trama FootPacket por ESP-NOW (broadcast) al hub
//
//  Que hace:
//   1) Lee el IMU (driver I2C minimo, sin librerias externas)
//   2) Fusiona a orientacion con filtro Mahony (6 ejes)
//   3) Detecta contacto (FSR) e integra la velocidad del pie
//      con ZUPT (zero-velocity update) para matar la deriva
//   4) Calcula la velocidad de deslizamiento HACIA ATRAS y el
//      rumbo del pie -> los envia al hub
//
//  Librerias Arduino usadas: Wire, WiFi, esp_now  (todas de serie
//  en el core arduino-esp32). NO requiere libs de terceros.
// ============================================================
#include <Wire.h>
#include <WiFi.h>
#include <esp_now.h>
#include "openomni_protocol.h"

// ---------- CONFIGURA ESTO ----------
#define THIS_FOOT     FOOT_LEFT     // FOOT_LEFT en un tracker, FOOT_RIGHT en el otro
#define PIN_SDA       8
#define PIN_SCL       9
#define PIN_FSR       3             // ADC del sensor de presion de talon
#define PIN_LED       10            // LED de estado
#define PIN_VBAT      2             // ADC divisor de bateria (opcional)
#define MPU_ADDR      0x68          // 0x68 (AD0=GND) o 0x69

// ---------- Registros MPU-9250/6500 ----------
#define REG_WHOAMI    0x75
#define REG_PWR1      0x6B
#define REG_SMPLRT    0x19
#define REG_CONFIG    0x1A
#define REG_GYRO_CFG  0x1B
#define REG_ACC_CFG   0x1C
#define REG_ACC_CFG2  0x1D
#define REG_ACCEL_XH  0x3B

// Escalas elegidas: accel +/-4g (8192 LSB/g), gyro +/-500dps (65.5 LSB/dps)
const float ACC_LSB = 8192.0f;
const float GYR_LSB = 65.5f;
const float G       = 9.80665f;

// ---------- Estado de fusion Mahony ----------
float q0=1, q1=0, q2=0, q3=0;
const float twoKp = 2.0f * 0.9f;   // ganancia proporcional
const float twoKi = 2.0f * 0.01f;  // ganancia integral
float integralFBx=0, integralFBy=0, integralFBz=0;

// ---------- Estado de locomocion ----------
float velX=0, velY=0;              // velocidad horizontal del pie en el mundo (m/s)
uint32_t lastZupt=0;
uint8_t  seq=0;

// ---------- Peer ESP-NOW (broadcast: sin necesidad de MAC) ----------
uint8_t peerBcast[6] = {0xFF,0xFF,0xFF,0xFF,0xFF,0xFF};

// ------------------------------------------------------------
//  Driver I2C minimo del IMU
// ------------------------------------------------------------
void wr(uint8_t reg, uint8_t val){ Wire.beginTransmission(MPU_ADDR); Wire.write(reg); Wire.write(val); Wire.endTransmission(); }
uint8_t rd(uint8_t reg){ Wire.beginTransmission(MPU_ADDR); Wire.write(reg); Wire.endTransmission(false);
                         Wire.requestFrom(MPU_ADDR,1); return Wire.read(); }

bool imuInit(){
    uint8_t who = rd(REG_WHOAMI);          // 0x71 MPU9250, 0x70 MPU6500, 0x73 MPU9255
    if (who!=0x71 && who!=0x70 && who!=0x73) return false;
    wr(REG_PWR1, 0x00);  delay(10);        // despierta
    wr(REG_PWR1, 0x01);  delay(10);        // reloj PLL del gyro
    wr(REG_CONFIG,   0x03);                // DLPF 41 Hz
    wr(REG_SMPLRT,   0x04);                // 200 Hz (1kHz/(1+4))
    wr(REG_GYRO_CFG, 0x08);                // +/-500 dps
    wr(REG_ACC_CFG,  0x08);                // +/-4 g
    wr(REG_ACC_CFG2, 0x03);                // accel DLPF 41 Hz
    delay(10);
    return true;
}

// Lee accel (g) y gyro (rad/s)
void imuRead(float &ax,float &ay,float &az,float &gx,float &gy,float &gz){
    Wire.beginTransmission(MPU_ADDR); Wire.write(REG_ACCEL_XH); Wire.endTransmission(false);
    Wire.requestFrom(MPU_ADDR,14);
    int16_t axr=(Wire.read()<<8)|Wire.read();
    int16_t ayr=(Wire.read()<<8)|Wire.read();
    int16_t azr=(Wire.read()<<8)|Wire.read();
    Wire.read(); Wire.read();               // descarta temperatura
    int16_t gxr=(Wire.read()<<8)|Wire.read();
    int16_t gyr=(Wire.read()<<8)|Wire.read();
    int16_t gzr=(Wire.read()<<8)|Wire.read();
    ax=axr/ACC_LSB; ay=ayr/ACC_LSB; az=azr/ACC_LSB;
    gx=(gxr/GYR_LSB)*DEG_TO_RAD; gy=(gyr/GYR_LSB)*DEG_TO_RAD; gz=(gzr/GYR_LSB)*DEG_TO_RAD;
}

// ------------------------------------------------------------
//  Filtro Mahony AHRS (6 ejes: accel + gyro)
// ------------------------------------------------------------
void mahonyUpdate(float gx,float gy,float gz,float ax,float ay,float az,float dt){
    float recipNorm;
    float halfvx,halfvy,halfvz;
    float halfex,halfey,halfez;

    if(!(ax==0 && ay==0 && az==0)){
        recipNorm = 1.0f/sqrtf(ax*ax+ay*ay+az*az); ax*=recipNorm; ay*=recipNorm; az*=recipNorm;
        // gravedad estimada desde el quaternion
        halfvx = q1*q3 - q0*q2;
        halfvy = q0*q1 + q2*q3;
        halfvz = q0*q0 - 0.5f + q3*q3;
        // error = producto cruz medido x estimado
        halfex = (ay*halfvz - az*halfvy);
        halfey = (az*halfvx - ax*halfvz);
        halfez = (ax*halfvy - ay*halfvx);
        if(twoKi>0.0f){
            integralFBx += twoKi*halfex*dt; integralFBy += twoKi*halfey*dt; integralFBz += twoKi*halfez*dt;
            gx += integralFBx; gy += integralFBy; gz += integralFBz;
        }
        gx += twoKp*halfex; gy += twoKp*halfey; gz += twoKp*halfez;
    }
    // integra el rate de giro
    gx*=0.5f*dt; gy*=0.5f*dt; gz*=0.5f*dt;
    float qa=q0, qb=q1, qc=q2;
    q0 += (-qb*gx - qc*gy - q3*gz);
    q1 += ( qa*gx + qc*gz - q3*gy);
    q2 += ( qa*gy - qb*gz + q3*gx);
    q3 += ( qa*gz + qb*gy - qc*gx);
    recipNorm = 1.0f/sqrtf(q0*q0+q1*q1+q2*q2+q3*q3);
    q0*=recipNorm; q1*=recipNorm; q2*=recipNorm; q3*=recipNorm;
}

float yawDeg(){ return atan2f(2.0f*(q0*q3+q1*q2), 1.0f-2.0f*(q2*q2+q3*q3)) * RAD_TO_DEG; }

// Acelera el vector body -> mundo (solo lo que necesitamos: componentes horizontales)
void bodyAccelToWorld(float ax,float ay,float az,float &wx,float &wy,float &wz){
    // R * a  (R = matriz de rotacion del quaternion)
    wx = (1-2*(q2*q2+q3*q3))*ax + 2*(q1*q2-q0*q3)*ay + 2*(q1*q3+q0*q2)*az;
    wy = 2*(q1*q2+q0*q3)*ax + (1-2*(q1*q1+q3*q3))*ay + 2*(q2*q3-q0*q1)*az;
    wz = 2*(q1*q3-q0*q2)*ax + 2*(q2*q3+q0*q1)*ay + (1-2*(q1*q1+q2*q2))*az;
}

// ------------------------------------------------------------
uint8_t readBattery(){
    int raw = analogRead(PIN_VBAT);
    float v = (raw/4095.0f)*3.3f*2.0f;      // divisor 1:1
    int pct = (int)((v-3.3f)/(4.2f-3.3f)*100.0f);
    return constrain(pct,0,100);
}

void sendPacket(float heading,float speed,uint8_t contact){
    FootPacket p;
    p.preamble=OO_PREAMBLE; p.version=OO_VERSION; p.foot=THIS_FOOT; p.seq=seq++;
    p.heading=heading; p.speed=speed; p.contact=contact; p.battery=readBattery();
    p.crc=oo_crc16((uint8_t*)&p, sizeof(FootPacket)-sizeof(uint16_t));
    esp_now_send(peerBcast, (uint8_t*)&p, sizeof(p));
}

// ------------------------------------------------------------
void setup(){
    Serial.begin(115200);
    pinMode(PIN_LED, OUTPUT);
    analogReadResolution(12);
    Wire.begin(PIN_SDA, PIN_SCL, 400000);

    if(!imuInit()){ // LED parpadeo rapido = fallo de IMU
        while(1){ digitalWrite(PIN_LED,!digitalRead(PIN_LED)); delay(80); }
    }

    WiFi.mode(WIFI_STA);
    if(esp_now_init()!=ESP_OK){ Serial.println("ESP-NOW fail"); ESP.restart(); }
    esp_now_peer_info_t peer={}; memcpy(peer.peer_addr,peerBcast,6);
    peer.channel=0; peer.encrypt=false; esp_now_add_peer(&peer);

    digitalWrite(PIN_LED, HIGH); // verde fijo = OK (como el Omni One)
    lastZupt=millis();
}

uint32_t lastMicros=0, lastTx=0;

void loop(){
    // dt real
    uint32_t now=micros();
    float dt=(lastMicros==0)?0.005f:(now-lastMicros)*1e-6f; lastMicros=now;
    if(dt<=0 || dt>0.1f) dt=0.005f;

    float ax,ay,az,gx,gy,gz;
    imuRead(ax,ay,az,gx,gy,gz);
    mahonyUpdate(gx,gy,gz,ax,ay,az,dt);

    // aceleracion lineal en el mundo (quita la gravedad)
    float wx,wy,wz; bodyAccelToWorld(ax,ay,az,wx,wy,wz);
    wx*=G; wy*=G; wz=(wz-1.0f)*G;               // resta 1g en Z-mundo
    float amag=sqrtf(wx*wx+wy*wy);

    // FSR: contacto con el cuenco
    int fsr=analogRead(PIN_FSR);
    bool contact = fsr > 400;                    // umbral ~ ajustar

    // Integra velocidad horizontal
    velX += wx*dt; velY += wy*dt;

    // ZUPT: si hay contacto y casi no hay aceleracion, el pie esta quieto -> resetea deriva
    if(contact && amag < 0.6f){
        if(millis()-lastZupt > 40){ velX*=0.5f; velY*=0.5f; }  // decaimiento suave
    } else { lastZupt=millis(); }
    // fuga lenta para evitar runaway si se pierde el ZUPT
    velX*=0.995f; velY*=0.995f;

    // Rumbo del pie y velocidad de deslizamiento HACIA ATRAS
    float yaw=yawDeg();
    float fwdx=cosf(yaw*DEG_TO_RAD), fwdy=sinf(yaw*DEG_TO_RAD);
    float vForward = velX*fwdx + velY*fwdy;      // + = adelante, - = atras
    float backSpeed = (vForward < 0) ? -vForward : 0.0f;  // el deslizamiento hacia atras = caminar
    backSpeed = constrain(backSpeed, 0.0f, 3.5f);

    // Envia a 100 Hz
    if(millis()-lastTx >= 10){
        lastTx=millis();
        sendPacket(yaw, contact?backSpeed:0.0f, contact?1:0);
    }
}

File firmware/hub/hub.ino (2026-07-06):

// ============================================================
//  OpenOmni - HUB receptor / puente a la PC
//  MCU : ESP32-S3  (USB nativo -> se presenta como MANDO USB HID)
//
//  Que hace:
//   1) Recibe las tramas FootPacket de ambos pies por ESP-NOW
//   2) Valida CRC y descarta pies "en el aire"
//   3) Fusiona a un vector de locomocion 2D (magnitud=velocidad,
//      direccion=rumbo del pie)  -> "soft decoupling": el rumbo
//      viene de los PIES, no de la cabeza
//   4) Lo emite como stick izquierdo de un gamepad USB estandar
//      => funciona con SteamVR y con cualquier juego, SIN driver
//
//  Boton BOOT (GPIO0): recalibra el "adelante" al rumbo actual.
//
//  Requiere: arduino-esp32 core 3.x, placa ESP32-S3, USB Mode =
//  "USB-OTG (TinyUSB)".  Librerias USB/USBHIDGamepad de serie.
// ============================================================
#include <WiFi.h>
#include <esp_now.h>
#include "openomni_protocol.h"

// 1 = ESP32-S3, salida como MANDO USB HID (sin driver en PC)
// 0 = ESP32 normal, saca "LOC x y run" por Serial -> usa pc_bridge.py
#define USE_USB_HID 1

#if USE_USB_HID
  #include "USB.h"
  #include "USBHIDGamepad.h"
  USBHIDGamepad gamepad;
#endif

// ---------- Parametros de locomocion ----------
const float MAX_SPEED   = 2.8f;   // m/s que mapea a stick full
const float DEADZONE    = 0.12f;  // m/s por debajo = quieto
const float RUN_THRESH  = 1.6f;   // m/s -> pulsa boton "correr"
const uint32_t TIMEOUT_MS = 200;  // sin datos -> stick a cero
#define PIN_CALIB 0               // boton BOOT

// ---------- Estado por pie ----------
struct FootState { float heading; float speed; bool contact; uint32_t t; uint8_t lastSeq; };
volatile FootState feet[2] = {{0,0,false,0,0},{0,0,false,0,0}};

float forwardRef = 0.0f;          // rumbo considerado "adelante" (calibrable)
float smX=0, smY=0;               // stick suavizado

// ---------- Callback de recepcion ESP-NOW (core 3.x) ----------
void onRecv(const esp_now_recv_info_t *info, const uint8_t *data, int len){
    if(len != sizeof(FootPacket)) return;
    FootPacket p; memcpy(&p, data, sizeof(p));
    if(p.preamble!=OO_PREAMBLE || p.version!=OO_VERSION) return;
    uint16_t crc = oo_crc16((uint8_t*)&p, sizeof(FootPacket)-sizeof(uint16_t));
    if(crc != p.crc) return;                     // trama corrupta
    if(p.foot>1) return;
    feet[p.foot].heading = p.heading;
    feet[p.foot].speed   = p.speed;
    feet[p.foot].contact = p.contact;
    feet[p.foot].t       = millis();
    feet[p.foot].lastSeq = p.seq;
}

void setup(){
    Serial.begin(115200);
    pinMode(PIN_CALIB, INPUT_PULLUP);

#if USE_USB_HID
    gamepad.begin();
    USB.begin();
#endif

    WiFi.mode(WIFI_STA);
    if(esp_now_init()!=ESP_OK){ Serial.println("ESP-NOW fail"); ESP.restart(); }
    esp_now_register_recv_cb(onRecv);
    Serial.println("OpenOmni hub listo (mando USB)");
}

// Elige el pie "activo" = en contacto y mas rapido (pie de apoyo que desliza)
int activeFoot(){
    uint32_t now=millis();
    bool l = feet[0].contact && (now-feet[0].t < TIMEOUT_MS);
    bool r = feet[1].contact && (now-feet[1].t < TIMEOUT_MS);
    if(l && r) return (feet[0].speed >= feet[1].speed) ? 0 : 1;
    if(l) return 0;
    if(r) return 1;
    return -1;
}

int8_t clamp127(float v){ if(v>127)v=127; if(v<-127)v=-127; return (int8_t)v; }

void loop(){
    // recalibracion del "adelante"
    static uint32_t calibHold=0;
    if(digitalRead(PIN_CALIB)==LOW){
        if(calibHold==0) calibHold=millis();
        if(millis()-calibHold>300){
            int f=activeFoot(); if(f<0) f=0;
            forwardRef = feet[f].heading;
            Serial.printf("Calibrado adelante = %.1f deg\n", forwardRef);
            calibHold=0; delay(200);
        }
    } else calibHold=0;

    // vector de locomocion
    float tx=0, ty=0; bool running=false;
    int f=activeFoot();
    if(f>=0){
        float speed=feet[f].speed;
        if(speed>DEADZONE){
            float m = constrain(speed/MAX_SPEED, 0.0f, 1.0f);
            float off = (feet[f].heading - forwardRef) * DEG_TO_RAD;  // desacople de rumbo
            // adelante = -Y (arriba del stick), strafe = X
            tx =  sinf(off) * m;
            ty = -cosf(off) * m;
            running = speed > RUN_THRESH;
        }
    }

    // suavizado (lowpass) para quitar el temblor de la zancada
    smX += (tx - smX)*0.35f;
    smY += (ty - smY)*0.35f;

    int8_t gx = clamp127(smX*127.0f);
    int8_t gy = clamp127(smY*127.0f);
    uint16_t buttons = running ? 0x0001 : 0x0000;   // boton 1 = correr/sprint

#if USE_USB_HID
    // send(x, y, z, rz, rx, ry, hat, buttons) - solo usamos stick izq + boton
    gamepad.send(gx, gy, 0, 0, 0, 0, 0, buttons);
    // telemetria opcional
    static uint32_t dbg=0;
    if(millis()-dbg>250){ dbg=millis();
        Serial.printf("foot=%d X=%d Y=%d run=%d\n", f, gx, gy, running);
    }
#else
    // Modo Serial para pc_bridge.py: linea "LOC <x> <y> <run>" (x,y en -127..127)
    Serial.printf("LOC %d %d %d\n", gx, gy, running?1:0);
#endif
    delay(5);   // ~200 Hz
}

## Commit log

2026-07-06 OpenOmni: DIY omnidirectional VR treadmill (BOM, fuerzas, CAD, firmware, webapp)
    Clon imprimible/madera del Virtuix Omni One:
    - docs/: lista de componentes, diagrama de fuerzas + hidraulica + IK, referencia WoODT (octagono)
    - cad/: modelo OpenSCAD parametrico + STL de piezas imprimibles
    - firmware/: trackers de pie (ESP32+IMU+FSR), hub (mando USB), protocolo, pc_bridge.py
    - index.html: gemelo digital interactivo Three.js (humanoide, fuerzas, ensamblaje, gas strut)
    [arm_hub.stl, bowl.stl, openomni.scad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]
2026-07-06 webapp: mochila en la espalda, vista explotada ordenada, arranque desmontado, tooltips de fuerza, contacto de pies y agachado
    - Fix: la placa de la mochila ahora se ancla a la ESPALDA (+X, lado del poste), no al costado
    - Brazo IK con eslabones mas largos (0.7/0.7) para alcanzar la espalda en todo el rango de altura
    - Vista explotada reordenada por subsistema (petalos del cuenco, base abajo, poste/brazo al lado, humano aparte)
    - Arranca DESMONTADO; el boton Ensamblar lo construye
    - Tooltips hover en las flechas de fuerza (descripcion + valor en N)
    - Colision de pies con el cuenco (no lo atraviesan) + caminar agachado segun inclinacion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
2026-07-06 webapp: placa de mochila pegada plana a la espalda + camara frontal
    - La placa de la mochila ahora es hija del ancla de la espalda (cara plana flush contra el torso), ya no hereda la rotacion del brazo
    - El extremo del brazo pasa a ser una pinza pequena que engancha la placa
    - Camara inicial de FRENTE al humanoide; el humano explota hacia arriba (queda centrado y visible)
2026-07-06 webapp: camara frontal + nariz de orientacion + lastre oculto + deep-link #go/#fall
    - Camara inicial de frente al humanoide mostrando tambien el brazo/gas strut
    - Nariz que marca el frente (-X) para desambiguar orientacion
    - Lastre bajado bajo la base (ya no asoma por el cuenco)
    - Deep-links #go (ensamblado) y #fall (dejarse caer) para capturas/compartir estado
2026-07-06 webapp: corrige ejes del humanoide (brazos/piernas en Z), el brazo hidraulico ya no se solapa con el brazo derecho
    - Hombros/caderas ahora en ±Z (izq/der); frente = -X
    - Zancada y agachado rotan sobre Z (adelante/atras)
    - Pie apunta al frente (largo en X)
2026-07-06 webapp: integra maniqui Xbot (GLB rigged) con animacion de caminar real; escala corregida
    - Reemplaza el muneco de primitivas por Xbot (three.js, CC0) cargado desde CDN
    - Animacion Walk real via AnimationMixer
    - Altura medida por extension del esqueleto (bbox de skinned mesh no es fiable) -> ~1.75 m
    - Mochila anclada a la columna (hueso spine2); fuerzas ancladas a cadera/pies
    - Inclinacion via grupo tilt; contacto de pies con offset de tobillo
    - Utilidad tools/model_preview.html para previsualizar modelos GLB
2026-07-07 webapp: brazo sobre carro rotatorio central (bearing bajo plataforma) que gira con la persona; maniqui azul; loader de modelo local (Y Bot); explotado reordenado; deep-links turn/lean
    - El brazo/poste ahora giran 360 en torno al eje CENTRAL sobre un slewing bearing (no desde el borde)
    - solveArm usa la posicion mundial del pivote y resta la rotacion del carro
    - Carga assets/character.glb si existe (tu Y Bot de Mixamo), si no cae al Xbot del CDN
    - Maniqui recoloreado azul tipo Mixamo
    - Explotado reordenado; ?turn= y ?lean= para capturas
2026-07-07 webapp: mecanismo de giro VISIBLE (anillo turntable perimetral) + seccion Componentes con links de compra Chile
    - El giro del brazo ahora es un anillo giratorio visible a ras de piso (turntable) con rodillos, ya no enterrado bajo el cuenco
    - Nuevo modal 'Componentes (Chile)': cada pieza con descripcion + links de busqueda a Sodimac/MercadoLibre/AliExpress e 'Imprimir 3D'
    - Nota: los soportes impresos son solo abrazadera/locator; el perno de acero aguanta la carga
    - Deep-link #buy abre el modal
2026-07-07 giro con BEARING CENTRAL (no anillo perimetral) + plataforma elevada sobre patas (mecanismo visible); gas strut modelado en OpenSCAD
    - Vuelve al bearing central unico (facil/suave); plataforma sobre 6 patas -> hueco visible con pedestal+bearing+spider+poste
    - Contacto de pies y fuerzas ajustados a la plataforma elevada (DECK)
    - cad/gas_strut.scad: resorte de gas parametrico con CORTE (gas N2 + aceite + piston + vastago) y modulo mount (abrazadera impresa + perno M8 pasante)
    [gas_strut.scad, gas_strut.stl]
2026-07-07 webapp: arranca ensamblado; patas ancladas a marco inferior; poste FUERA del cuenco (no lo atraviesa); gas strut puentea el codo (ley de cosenos); gajos explotados simetricos; texto de ayuda sin choc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
2026-07-07 cad: overhaul de juntas impresas realistas (joints.scad): clamp partido con tuerca embebida + perno pasante, codo con horquilla/hoja + pin de acero, placa de mochila con rotula, clamp de hub con asie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
    [j_clamp.stl, j_elbow.stl, j_hub.stl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]
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2026-07-07 webapp: giro = anillo/collar SOLIDO giratorio (turntable) estilo Omni One, no rieles/ruedas; base redonda integrada. docs: planilla de costos Antofagasta CLP (xlsx con formulas + csv), enlazada en el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
    [costos-antofagasta-clp.csv, costos-antofagasta-clp.xlsx]
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2026-07-08 webapp: visualizador de presupuesto (2 escenarios, baja el costo a la mitad) + torre de giro con ingeniería real
    - Visualizador de costos (botón 💰 Costos): tarjetas Máximo vs Económico
    ($612.000 → $282.000 CLP, −54%), barras por subsistema y tabla de "cómo bajar
    cada ítem". Descarga Excel/CSV. Deep-link #cost. Datos en docs/costos.json.
    - Remodelado del mecanismo como RODAMIENTO DE GIRO CENTRAL (slewing ring) con
    DOS caminos de carga separados: el peso del usuario baja por un pedestal central
    fijo (por el bore del rodamiento) a la placa base; el rodamiento solo toma el
    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
    [costos-antofagasta-clp.csv, costos-antofagasta-clp.xlsx]
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2026-07-08 webapp: arregla el resorte de gas flotante — geometría con eje en X + strut telescópico anclado a los dos puntos del codo (cuerpo desde A, vástago desde B); rótulas en los extremos
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
